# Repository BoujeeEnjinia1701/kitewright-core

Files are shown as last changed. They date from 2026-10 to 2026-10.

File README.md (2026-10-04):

# Kitewright Core

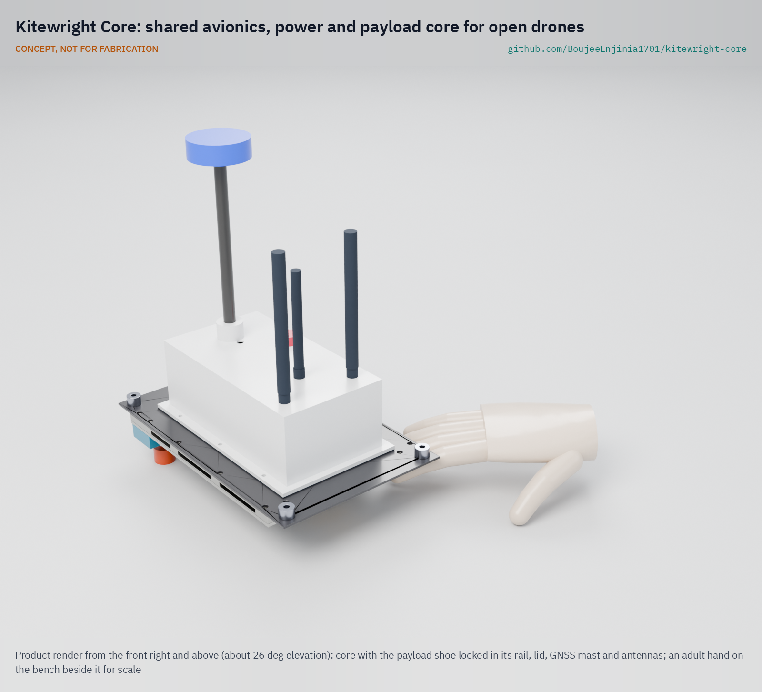
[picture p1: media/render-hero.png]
Kitewright Core: shared avionics, power and payload core, product render


     

**Area:** Aerial robotics · **TRL:** 3 of 9 (proof of concept on paper) · **Value-engineering target:** USD 5,000; estimated cost USD 3,946.80 · **Difficulty:** 4 of 5

The shared core of the Kitewright open drone family: open autopilot, ColdCell power bus and one standard payload mount.

## Concept rationale

Kitewright is an open civilian drone family built so that one set of avionics, one power bus and one payload mount serve every frame and every payload. Kitewright Core is that shared part: an autopilot running PX4 (ArduPilot as an alternative), a ColdCell power bus, radio links, a ground station setup and a single payload mount that carries both power and data. The Lift multirotor and the Range quadplane bolt onto it, and payloads such as AvalancheScout and LakeWatch plug into it. A fix or a tuning result found on one frame reaches all of them.

The core is tuned for the conditions that sparked the family: high, cold mountains such as Kashmir and the Himalaya, where Amish Chadha wants to fly. Our own first estimate is that at 5,000 m and -20 °C a multirotor hovers for only about 47% of its sea-level time (estimate, combining thinner air with cold battery capacity; to be checked on AltiRig). The core therefore treats cold power, altitude tuning and conservative failsafes as design inputs, not afterthoughts. The payload mount follows the open Pixhawk Payload Bus standard, DS-014, with a plain rail and locking pin, so third-party payloads can follow a published interface.

## Burning platform

Drones already save lives: DJI counted more than 1,000 people rescued with drone help worldwide by July 2023 ([DJI, 2023](https://www.dji.com/media-center/announcements/dji-records-more-than-1000-people-rescued-by-drones-globally)). In the high mountains they also carry loads: in April 2024 an unmodified DJI FlyCart 30 carried 15 kg between Everest Base Camp and Camp 1, at 5,300 to 6,000 m and -15 to 5 °C, in a 12 minute round trip that takes Sherpas 6 to 8 hours on foot through the icefall ([DJI, 2024](https://www.dji.com/media-center/announcements/dji-completes-world-first-drone-delivery-tests-on-mount-everest-en)). India has 189 high-risk glacial lakes above 4,500 m that field teams can reach only from June to September ([ThePrint, 2024](https://theprint.in/india/govt-approves-rs-150-crore-for-glacial-lake-outburst-flood-risk-mitigation-programme-for-4-states/2232525/)).

The platforms that can work there are closed and costly. A DJI Matrice 350 RTK costs USD 14,814 and uses its own payload and battery system ([Advexure](https://advexure.com/products/dji-matrice-350-rtk)); its self-heating TB65 batteries cost USD 899 each and are used in pairs ([DroneFly](https://www.dronefly.com/products/dji-tb65-intelligent-flight-battery-m350)). Air at 5,000 m in the standard atmosphere has a density of 0.736 kg/m3, 60% of sea level, and a temperature of -17.5 °C ([Engineering ToolBox](https://www.engineeringtoolbox.com/standard-atmosphere-d_604.html)). Open parts exist, such as PX4, licensed BSD 3-Clause ([PX4 on GitHub](https://github.com/PX4/PX4-Autopilot)), and the Pixhawk Payload Bus standard ([Dronecode, 2021](https://dronecode.org/announcing-the-pixhawk-payload-bus-open-standard/)), but no open core combines them into a documented, cold-rated base that a whole family of frames and payloads can share.

## Where it could be used

### By industry

| Industry | Use |
| --- | --- |
| Mountain and wilderness search and rescue | Search, thermal and transceiver payloads on a shared core that works at altitude |
| Disaster response and civil protection | Survey, line drop and supply delivery after floods and landslides |
| Glaciology, hydrology and climate research | Glacial lake and snowpack survey payloads (LakeWatch) on an open, inspectable platform |
| Mountain infrastructure (hydropower, roads, utilities) | Inspection and monitoring in high valleys |
| Universities and makerspaces | A documented reference core for teaching and payload development |

### By country or region

| Country or region | Why it matters there |
| --- | --- |
| India (Kashmir Himalaya) | A 2026 inventory found 155 glacial lakes, five with very high outburst susceptibility that threaten several thousand buildings, 15 major bridges and a hydropower project ([Journal of Glaciology, 2026](https://www.cambridge.org/core/journals/journal-of-glaciology/article/glacial-lake-outburst-flood-susceptibility-and-potential-downstream-implications-across-the-kas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)). |
| India (Himalayan states) | The national programme covers 189 high-risk lakes above 4,500 m, reachable on foot only from June to September ([ThePrint, 2024](https://theprint.in/india/govt-approves-rs-150-crore-for-glacial-lake-outburst-flood-risk-mitigation-programme-for-4-states/2232525/)); India's Drone Rules 2021 set the categories and Digital Sky process a civilian drone must follow ([PIB](https://static.pib.gov.in/writereaddata/specificdocs/documents/2022/jan/doc202212810701.pdf)). |
| Pakistan (Karakoram) | A small drone found Rick Allen alive on Broad Peak after 36 hours in 2018 ([Explorersweb, 2018](https://explorersweb.com/rick-allen-found-alive-on-broad-peak/)). |
| Nepal | Drone deliveries on Everest were tested at 5,300 to 6,000 m in 2024 and contracted by the government from May 2024 ([DJI, 2024](https://www.dji.com/media-center/announcements/dji-completes-world-first-drone-delivery-tests-on-mount-everest-en)). |
| United States | An average of 27 people a year have died in avalanches over the past decade ([CAIC](https://avalanche.state.co.us/accidents/statistics-and-reporting)); civilian drones there fly under FAA Part 107 ([FAA](https://www.faa.gov/uas/media/Part_107_Summary.pdf)). |

## What sparked the idea

In July 2018 the climber Rick Allen went missing high on Broad Peak in the Karakoram after a fall while descending. After 36 hours, Bartek Bargiel, who was filming a ski descent of K2, flew a small drone over the slope, spotted Allen alive at about 7,500 m and guided climbers to him ([Explorersweb, 2018](https://explorersweb.com/rick-allen-found-alive-on-broad-peak/)). The drone was a DJI Mavic Pro, flown far above its rated ceiling ([DroneDJ, 2018](https://dronedj.com/2018/07/16/mountaineer-rick-allen-was-feared-dead-on-broad-peak-but-a-dji-mavic-pro-drone-found-him-alive/)). Kitewright starts from that flight: an open family of drones, sharing one core, built for the mountains where it happened.

## Problem

Mountain and disaster teams who want drones for search, survey and delivery must buy closed platforms whose batteries, mounts and payloads work only with one maker. There is no open, documented core that a frame and its payloads can share, and that is set up for thin, cold air.

Full problem statement: [docs/01-problem.md](docs/01-problem.md)

## Concept

The shared core of Kitewright, an open drone family: an open autopilot on PX4, a ColdCell power bus, one standard payload mount carrying power and data (Pixhawk DS-014 with a plain rail and locking pin), radio and ground station, used by the Lift and Range frames and every payload.

Full design precis: [docs/02-concept.md](docs/02-concept.md) · Requirements: [docs/03-requirements.md](docs/03-requirements.md) · Calculations: [docs/04-calcs/01-sizing.md](docs/04-calcs/01-sizing.md) · Prototype build plan: [docs/05-build-plan.md](docs/05-build-plan.md) · Design decisions: [docs/06-design-decisions.md](docs/06-design-decisions.md) · General arrangement: [cad/drawings/KWC-DWG-001.pdf](cad/drawings/KWC-DWG-001.pdf)

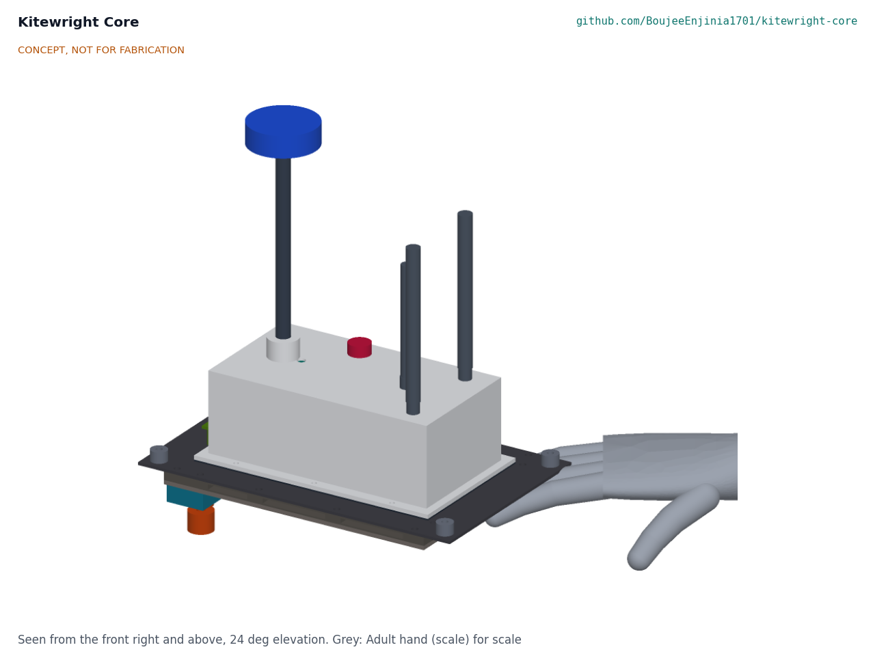
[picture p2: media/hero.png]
Concept, seen from the front right and above, with an adult hand for scale


At TRL 3 the core meets all eleven requirements on paper: the rail and two locking pins carry a 5 kg payload with factors of 8 or more, a gloved payload swap takes about 52 s, 100 W reaches the payload, and the avionics stay within their ratings from -20 to +45 °C. With a carbon fibre plate, lightened rails and the power leads moved into each frame's harness (Amish's decision of 2026-10-03), the core is estimated at 0.99 kg against R9's 1.0 kg. R8 is restated so that a core moving between Lift and Range has its frame's power harness resoldered at the bench (Amish's decision of 2026-10-04), and the frames now carry the core to one shared mounting envelope. The hover-time model gives 47 % of sea-level hover time at 5,000 m and -20 °C with cold packs and 70 % with ColdCell packs (estimates).

## Key components

- Flight controller (Pixhawk standard)
- GNSS receiver and compass
- ColdCell power bus and power distribution board
- Payload mount (plain rail, locking pin, DS-014 connector)
- Telemetry radio and control link
- Ground station kit
- Optional companion computer
- Cold-rated harness and avionics enclosure
- Altitude parameter sets

## Building the prototype

The prototype is one core: a 2 mm carbon fibre plate carrying the avionics under a printed lid, with a plain rail, two front stops and two spring locking pins underneath, and one payload shoe. Nine parts are made, the carbon plate by a cutting service and the others with a saw, drill, small mill, tap and 3D printer; everything else is bought, and each frame brings its own power leads. The [prototype build plan](docs/05-build-plan.md) gives a making sketch for every made part, close-ups of every joint, eleven assembly steps with pictures, first checks and safety stops. It is a plan, not yet built.

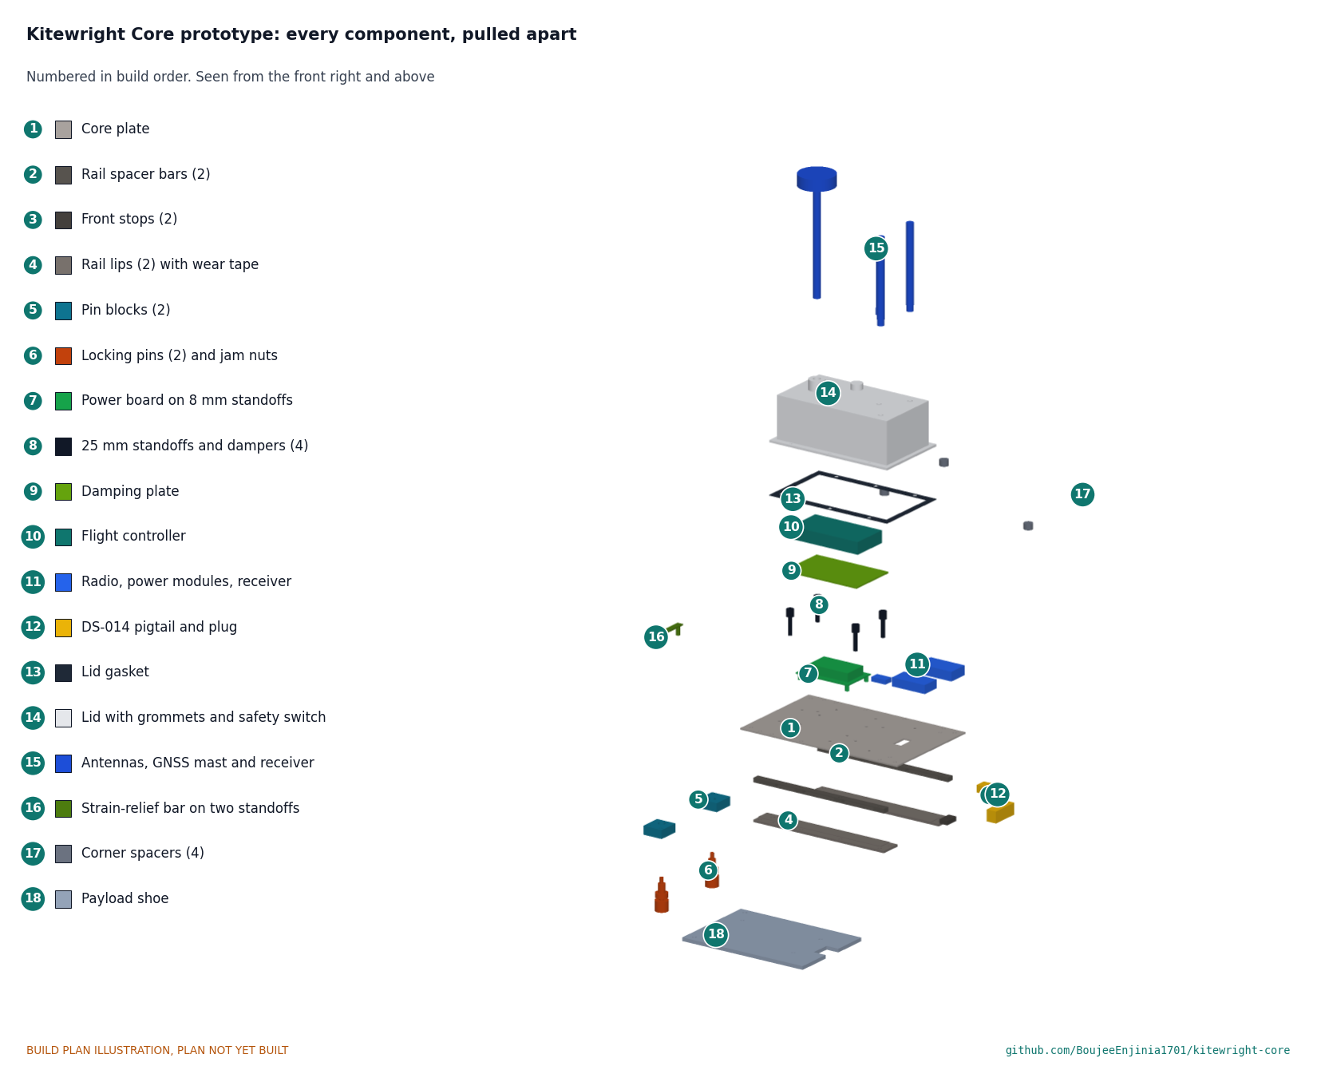
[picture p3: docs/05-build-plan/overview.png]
Every component, pulled apart and numbered in build order


## Safety

> Published as an open engineering reference, not certified aviation equipment.
>
> Civilian use only. No weapons, targeting or military payloads, and none will be accepted into the family.
>
> Certification and operating approvals (FAA Part 107 in the United States, EASA rules in Europe, India's DGCA Drone Rules 2021) are out of scope at this TRL and will be addressed if prototypes progress. Builders must fly only where local rules allow.
>
> Propellers can cause serious injury: arm only in a clear area, and write pre-flight, arming and keep-out procedures before any powered test.
>
> Lithium battery packs can catch fire after a crash, over-charge or cold charging; follow ColdCell safety rules. The core carries up to 60 V and 200 A peak: power it first from a current-limited bench supply, and connect packs only through the keyed anti-spark connectors.
>
> Loss of link or power in thin air can mean a crash in remote terrain: return-to-launch, low-battery and geofence failsafes must be set and tested at each altitude band.
>
> Payloads must be locked and pin-checked before flight; a released payload is a falling object. Two independent locking pins are fitted; neither may show its red band, and the payload is tugged, before every flight.
>
> This design is published as an open engineering reference. It is a TRL 3 concept, not for fabrication, and not certified equipment.

## Repository layout

| Folder | Contents |
| --- | --- |
| `docs/` | Problem, concept, requirements, calculations and design decisions |
| `cad/src/` | build123d Python source, the source of truth for all geometry |
| `cad/step/`, `cad/stl/` | Exported models for FreeCAD, other CAD tools and printing |
| `cad/drawings/` | 2D sketches and dimensioned drawings |
| `bom/` | Bill of materials |
| `electronics/` | KiCad schematics and PCB layouts |
| `firmware/` | Microcontroller code |
| `media/` | Renders, perspectives and photos |
| `build-log/` | Dated prototyping notes |

## Documentation

Controlled documents follow the portfolio [documentation standard](.kit/STANDARDS.md). Each carries a document ID (KWC-PRC-001 for the precis), a version and a revision history. Branded PDFs are built with `python .kit/render.py` and attached to GitHub Releases when a document is tagged, for example `KWC-PRC-001/v1.0`.

## Credits

Designed by Amish Chadha at Design Molecule Labs. See [CONTRIBUTORS.md](CONTRIBUTORS.md) for roles. To cite this design, use [CITATION.cff](CITATION.cff) (GitHub shows it as "Cite this repository").

AI assistance (Claude) was used to accelerate prototype documentation and first-pass research. Design direction and all decisions are Amish Chadha's, recorded in this repository's decision records (`docs/decisions/`).

## Licenses

- **Hardware** (CAD, drawings, BOM, electronics): [CERN-OHL-S v2](LICENSE)
- **Software** (firmware, scripts, notebooks): [MIT](LICENSE-SOFTWARE)

A project of the [Design Molecule](https://designmolecule.com) lab.

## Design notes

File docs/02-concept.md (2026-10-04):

---
doc_id: KWC-PRC-001
title: Kitewright Core design precis
project: Kitewright Core
doc_type: Precis
version: "0.3"
status: Draft
date: '2026-10-03'
author: Amish Chadha
license: CERN-OHL-S-2.0
revisions:
- version: "0.1"
  date: '2026-09-30'
  author: Amish Chadha
  change: Initial scaffold
- version: "0.2"
  date: '2026-10-03'
  author: Amish Chadha
  change: TRL 2 and TRL 3 precis on the constructable design; decisions of KWC-DDR-001 and KWC-DDR-002 under Amish's 2026-10-03 pre-approval; numbers from KWC-CAL-001
- version: "0.3"
  date: '2026-10-03'
  author: Amish Chadha
  change: Amish's decision 33B (KWC-DDR-003); carbon plate, power leads in the frames' harness; mass and cost from KWC-CAL-001 v0.2
---

# Kitewright Core design precis

The shared core of the Kitewright open drone family: open autopilot, ColdCell power bus and one standard payload mount.

## Summary

Kitewright Core is a 240 x 150 mm carbon fibre plate that hangs under a frame's deck on four M4 bolts. On top, under a printed lid that rises through an opening in the deck, sit a Pixhawk-standard flight controller on vibration dampers, a power distribution board for two ColdCell packs, two independent 5.3 V supplies, a payload power switch, a telemetry radio and a control link receiver. A GNSS receiver stands on a removable mast above the lid. Under the plate is the payload mount: a plain rail of aluminium bars in which a 5 mm payload shoe slides from the rear to two front stops and is held by two spring locking pins, with the DS-014 power and data plug on a short pigtail. The same core, unchanged, flies Kitewright Lift and Kitewright Range with published parameter sets for three altitude bands. On paper it meets all eleven requirements; its estimated mass is 0.99 kg against R9's 1.0 kg after Amish's decision 33B on 2026-10-03 (Figure 1, KWC-CAL-001).

Figure 1. Kitewright Core concept, seen from the front right and above, with an adult hand for scale

*Figure 1. Kitewright Core, generated from the parametric model. CONCEPT, NOT FOR FABRICATION.*

## How it works

ColdCell packs plug into the two AS150 inputs of the frame's power harness, which Kitewright Lift or Range supplies and which enters the lid at the back (decision 33B). The power distribution board joins them, measures total current with a Hall sensor and feeds the frame's speed controllers through two AS150 outputs. Two independent supplies, a digital power monitor and a backup supply, each turn the 18 to 60 V bus into 5.3 V for the flight controller, so one failure does not drop the avionics. A payload switch, enabled by the flight controller, feeds the bus to the payload's battery pins through the DS-014 pigtail with an 8 A limit.

The flight controller runs released PX4 with Kitewright parameter sets. It reads the packs' temperature and charge over DroneCAN from ColdCell's battery management system, the GNSS and compass on the mast, and the barometer on its own board, and it talks to the ground station over a 900 MHz class telemetry radio and to the pilot's handset over a long-range control link.

A payload carries a 184 x 128 x 5 mm aluminium shoe on its top. The operator pulls and twists both locking pins to their rest, slides the shoe into the rail from the rear until it stops against the front stops, and twists the pins back: they snap up into the shoe's two holes. The DS-014 plug is then pushed into the payload's socket, and the flight controller recognises the payload over MAVLink. The shoe's edges run between the plate and the taped lips with a 0.3 mm gap, so the lips carry its weight; the pins and front stops hold it fore and aft.

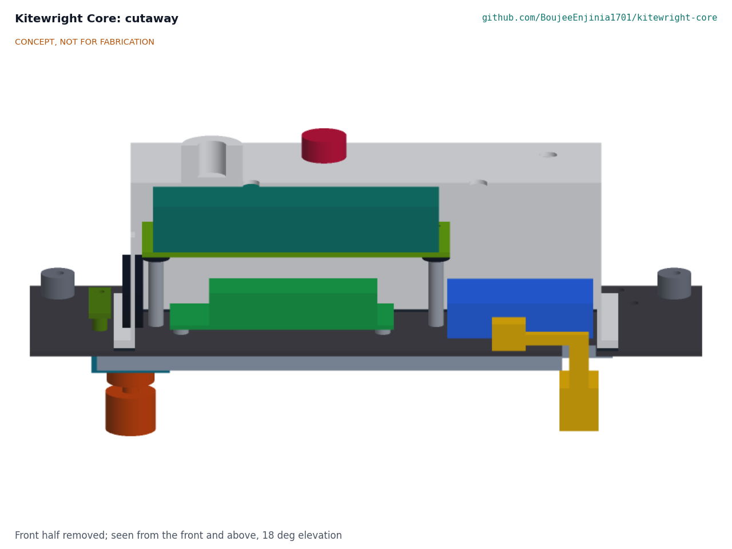
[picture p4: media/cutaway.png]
Figure 2. Cutaway on the centre line


*Figure 2. Cutaway, front half removed: the damped flight controller above the power board, and the rail and shoe below the plate.*

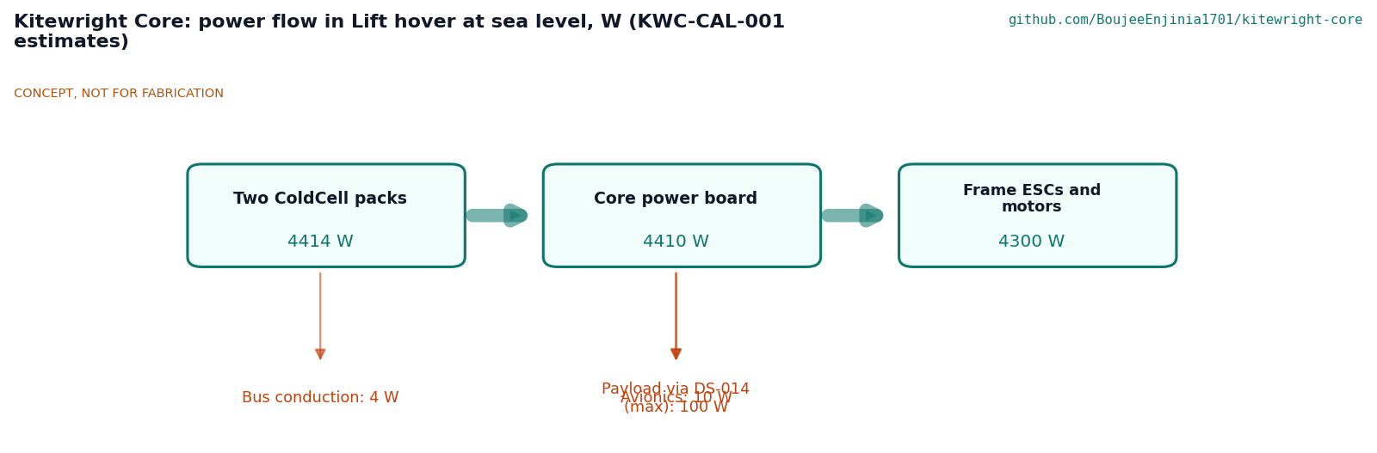
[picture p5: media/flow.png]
Figure 3. Power flow


*Figure 3. Power flow in Kitewright Lift's hover at sea level (KWC-CAL-001 estimates).*

## Main components

*Table 1. Components, numbered as in `bom/bom.csv` and Figure 4.*

| # | Component | Role |
| --- | --- | --- |
| 1 | Core plate, 240 x 150 x 2 mm carbon fibre | Carries everything; bolts to the frame on a 220 x 130 mm pattern |
| 2 | Corner spacers (4), 16 x 8 mm | Hold the plate 8 mm under the frame deck |
| 3, 4, 5 | Rail spacer bars, lips and wear tape | The plain rail: 200 mm long, 19 mm lip overlap, 0.3 mm running gap |
| 6 | Front stops (2) | End of travel, where both pins line up with their holes |
| 7, 8 | Pin blocks and locking pins (2) | Two independent spring plungers; a red band shows a withdrawn pin |
| 9 | Payload shoe | Fitted to every payload; the core kit carries one |
| 10, 11 | Lid and gasket | Printed ASA cover with mast boss, antenna, switch and grommet holes |
| 12, 13, 14 | Damping plate, dampers, standoffs | Isolate the flight controller from vibration |
| 15 | Flight controller, FMUv6X class | Runs PX4; triple IMU with heater; 16 outputs; Ethernet and CAN |
| 16, 17 | GNSS receiver and compass, mast | Position and heading, 231 mm above the plate, clear of power wiring |
| 18, 19 | Power distribution board, power modules | Pack inputs, frame outputs, current sensing, two 5.3 V supplies, payload switch |
| 20 | Clinch nuts (14) | Flush threads under the plate where the shoe slides |
| 21 | Strain-relief bar | Holds the frame's four 8 AWG power leads behind the lid; the leads and AS150 plugs belong to each frame (decision 33B) |
| 22, 23, 24 | Telemetry radio, control link receiver, antennas | Command, telemetry and control path |
| 25 | DS-014 connector pair and pigtail | Power and data to the payload |
| 26 to 29 | Safety switch, grommets, harness, fasteners | Arming safety, cable entries, cold-rated wiring |
| 30 | Companion computer (optional) | Payload processing in its own box on the frame, over Ethernet |
| 31 to 34 | Handset, ground station tablet, ground antenna, field charger | Ground station kit |
| 35 | Spares kit | Field spares |

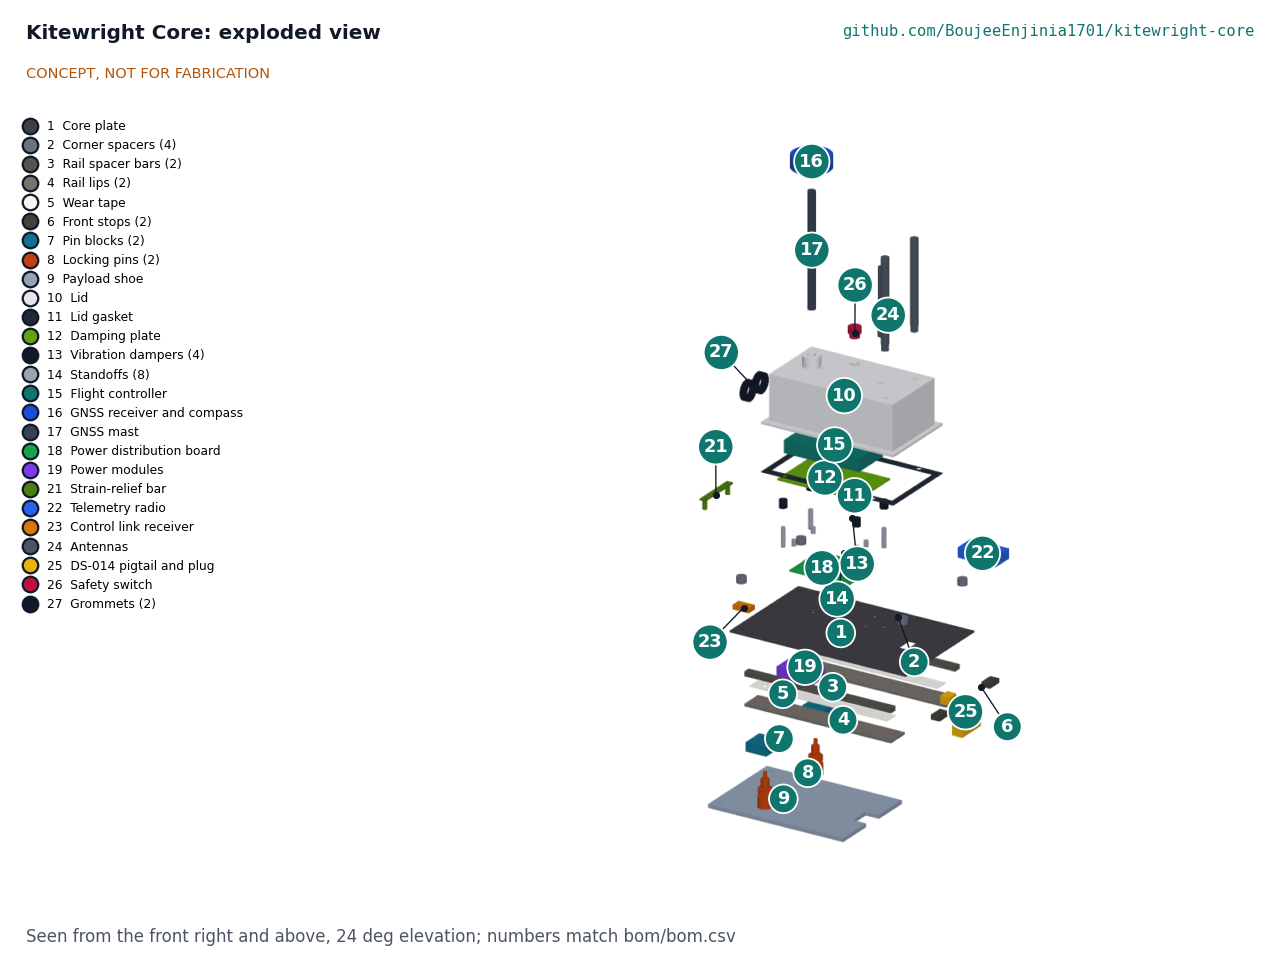
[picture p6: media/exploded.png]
Figure 4. Exploded view


*Figure 4. Exploded view; numbers match `bom/bom.csv`.*

## Numbers from the TRL 3 calculations

*Table 2. Key figures (KWC-CAL-001).*

| Quantity | Value | Basis |
| --- | --- | --- |
| Rated payload | 5 kg; vertical design load 147 N | R3 |
| Lowest strength factor | 10.8 (plate edge as a beam between frame bolts) | CAL section A |
| Fore-aft load on one pin alone | 221 N; 11.2 MPa shear in a 5 mm pin | CAL section A |
| Payload swap with gloves | About 52 s, no tools | CAL section B |
| Payload current for 100 W | 5.6 A at 18 V (6S), 2.2 A at 44.8 V | CAL section C |
| Hottest part at 45 °C ambient | About 75 °C (parts rated 85 °C) | CAL section D |
| Air density at 5,000 m | 0.736 kg/m³, 60 % of sea level | CAL section E |
| Hover time at 5,000 m and -20 °C | 47 % of sea level with cold packs; 70 % with ColdCell | CAL section F |
| Flight controller outputs used | Lift 11, Range 10, of 16 | CAL section G |
| Core mass | About 0.99 kg (R9 met on paper, 10 g margin) | CAL section H |
| Cost | USD 3,946.80 with ground station and spares | CAL section I |

Value-engineering target: USD 5,000. Estimated cost of the constructable design: USD 3,946.80 (USD 1,053.20 under the target).

## Key design choices

All decided under Amish's 2026-10-03 pre-approval; each is argued in KWC-DDR-001 or KWC-DDR-002 and indexed in the design decisions register, KWC-DEC-001.

- **PX4 first, ArduPilot as the documented alternative** (D1), on a Pixhawk FMUv6X class controller (D2).
- **One bus, 18 to 60 V** (D3), so a 6S Range and a 12S or 16S Lift use the same board, supplies and switch.
- **One payload class for version 1: 5 kg and 100 W** (D4).
- **Plain rail, rear entry, front stops, pigtail plug** (D5); no bayonet and no blind-mating connector.
- **Two independent locking pins** (D6), the conservative safety choice; either holds the payload alone.
- **Core hangs under the frame deck** (D7) on a 220 x 130 mm M4 pattern; the lid rises through a 200 x 112 mm opening.
- **Companion computer outside the core** (D8), so its heat and mass stay with the frames that need it.
- **ColdCell reports over DroneCAN** (D9), which released PX4 reads without changes.

## Patent design-arounds

From the preliminary patent, trademark and prior-art screen (not legal advice), all kept in the constructable design:

- Payload mount uses the Pixhawk DS-014 connector with a plain rail and locking pins, no bayonet, to stay clear of DJI US 2021/0316882 (payload mounting platform, claims unread). DJI US9890900B2 (quick gimbal connector) is expired.
- ColdCell packs use an external film heater on standard cells with a BMS thermostat, not in-cell resistor sheets (EC Power US9882197B2, to 2036). The core only reads the packs.
- Any tether input to the power bus is a fixed-voltage supply with onboard DC-DC conversion, not adaptive tether voltage (Elistair US11059580B2, to 2037). The core's 18 to 60 V inputs take a fixed-voltage tether converter like a pack.
- Attorney claim reads before any sale: DJI 2021/0316882, US9882197, US11059580.

## Relationship to other lab projects

- ColdCell (heated battery packs; reports over DroneCAN on the core's bus)
- AltiRig (thin-air propeller and motor test chamber; supplies the hover-thrust data for Table 6 of KWC-CAL-001)
- Kitewright Lift and Kitewright Range (host frames; provide the deck pattern and opening of D7)
- AvalancheScout and LakeWatch (payloads; each carries a shoe of KWC-DWG-106 and a DS-014 socket)

## Safety

> **Safety:** Published as an open engineering reference, not certified aviation equipment. Civilian use only. No weapons, targeting or military payloads, and none will be accepted into the family.
>
> **Safety:** Certification and operating approvals (FAA Part 107 in the United States, EASA rules in Europe, India's DGCA Drone Rules 2021) are out of scope at this TRL and will be addressed if prototypes progress. Builders must fly only where local rules allow.
>
> **Safety:** Lithium packs: the core carries up to 60 V and 200 A peak from two packs. Connect packs only through the anti-spark AS150 connectors, check polarity on a current-limited bench supply first, never charge a pack below its charge temperature (ColdCell blocks this), and keep a lithium fire plan at hand. A crashed pack can catch fire hours later.
>
> **Safety:** Moving machinery: propellers on the frames can cause serious injury. The core's safety switch must be pressed before arming; arm only in a clear area, and write pre-flight, arming and keep-out procedures before any powered test.
>
> **Safety:** Falling payload: a released payload is a falling object. Two independent locking pins are fitted; both must show no red band, and the payload is tugged, before every flight. Nobody stands under a payload being lifted.
>
> **Safety:** Loss of link or power in thin air can mean a crash in remote terrain: return-to-launch, low-battery and geofence failsafes must be set and tested at each altitude band (KWC-CAL-001, Table 6).

This design is published as an open engineering reference. It is not certified equipment.

## Open questions

None for design. Facts that can only be settled with parts in hand (the DS-014 licence, pinout and pin rating, the controller's mounting pattern, plunger stroke) are listed under "To confirm when parts are bought" in KWC-DEC-001. R9 core mass awaits Amish's decision (`docs/REVIEW.md`).

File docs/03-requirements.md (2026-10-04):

---
doc_id: KWC-REQ-001
title: Kitewright Core requirements
project: Kitewright Core
doc_type: Requirements
version: "0.4"
status: Draft
date: '2026-10-04'
author: Amish Chadha
license: CERN-OHL-S-2.0
revisions:
- version: "0.1"
  date: '2026-09-30'
  author: Amish Chadha
  change: Initial scaffold
- version: "0.2"
  date: '2026-10-03'
  author: Amish Chadha
  change: TRL 3 status of every requirement from KWC-CAL-001; rated payload class and bus voltage window stated (KWC-DDR-001); targets unchanged
- version: "0.3"
  date: '2026-10-03'
  author: Amish Chadha
  change: Amish's decision 33B carried out (KWC-DDR-003); status of R3, R8, R9 and R11 updated from KWC-CAL-001 v0.2; R9 now met on paper; targets unchanged; R8 harness point open (O2)
- version: "0.4"
  date: '2026-10-04'
  author: Amish Chadha
  change: R8 restated under Amish's round-3 decision 7A (KWC-DDR-004); register item O2 closed; all eleven requirements met on paper or by design
---

# Kitewright Core requirements

The requirements below are unchanged in their targets from version 0.1. Each carries its TRL 3 status from the sizing calculations, KWC-CAL-001 v0.2, on the constructable design of KWC-DDR-002 as lightened under decision 33B (KWC-DDR-003). On 2026-10-03 Amish decided R9 core mass as recommended ("i agree with all the 46 recommendations you provided. please proceed."): a lighter structure, with the power leads moved out of the core into the frames. All eleven requirements are met on paper or by design. On 2026-10-04 Amish decided R8 as recommended (round 3, item 7A): Amish Chadha (owner) on 2026-10-04: "For round 3, I agree with all your proposed recommendations". A core moved between Lift and Range now has its frame's power harness changed at the bench, and R8 is restated to say so (KWC-DDR-004).

> **Safety:** The core carries lithium pack power of up to 60 V and 200 A, and holds payloads that would fall if released in flight. Requirements R3 and R5 and the build plan's safety stops cover these; none of the figures here is a safety approval.

Table 1. Requirements

| ID | Requirement | Target | Verification (TRL 3 or later) | TRL 3 status (KWC-CAL-001) |
| --- | --- | --- | --- | --- |
| R1 | Payload electrical interface | DS-014 40-pin connector with all required signals and battery power present and documented | Continuity and protocol test with a reference payload on the bench | Met on paper; licence and pinout to confirm from the standard |
| R2 | Payload swap | Swap in 60 s or less without tools, with locking pin engaged and visible (target) | Timed field trials with gloved users | Met on paper: about 52 s with gloves (estimate) |
| R3 | Mount strength | Holds 3 times the rated payload mass statically and 1.5 times under a 2 g drop (target) | CalRig proof-load and drop test | Met on paper: factor 8 or more on every part at 147 N, carbon plate included |
| R4 | Payload power | At least 100 W continuous to the payload at bus voltage (target) | Load bank test at -20 and +45 °C | Met on paper: at most 5.6 A; DS-014 pin rating to confirm |
| R5 | Operating temperature | Avionics boot and fly from -20 to +45 °C (target) | Climatic chamber soak and bench run | Met on paper: hottest part about 75 °C, cold boot within rating |
| R6 | Altitude envelope | Stable control and failsafes at air density equivalent to 5,000 m (target) | AltiRig tests, then field flights at a high site | Met on paper for the core; flight check needs a frame |
| R7 | Performance model | Published hover time model predicts measured hover time within 15% at each altitude band (target) | Compare model to AltiRig and flight logs | Model published; accuracy shown only at TRL 4 |
| R8 | Common core | Same core flies Lift and Range with parameter changes and a change of the frame's power harness at the board (a bench change, lid off, about 30 min); restated 2026-10-04, decision 7A | Build both frames and fly from one core set; time the bench harness change | Met by design as restated: same firmware, same 220 x 130 mm fixing (Kitewright interface table), four 8 AWG leads resoldered at the board |
| R9 | Core mass | Avionics, radios and mount 1.0 kg or less, excluding batteries (target) | Weigh the assembled core | Met on paper: 0.99 kg estimated, 10 g margin (decision 33B); bought-part masses to confirm |
| R10 | Upstream firmware | Runs a released PX4 version with no source changes, parameters and modules only | Build check against the PX4 release tag | Met by design |
| R11 | Prototype cost | USD 5,000 or less including ground station and spares | Bill of materials and receipts | USD 3,946.80, under the value-engineering target by USD 1,053.20 |

## Definitions fixed at TRL 3

- **Rated payload:** 5 kg on the mount, one payload class for version 1, so R3's load cases are 147 N vertical (KWC-DDR-001, D4).
- **Bus voltage:** 18 to 60 V at the core's pack inputs, from 6S Li-ion to 16S LiFePO4 (KWC-DDR-001, D3).
- **Core mass (R9):** the airborne core as built, excluding batteries, the payload shoe (each payload carries its own), the optional companion computer (carried outside the core, KWC-DDR-001, D8) and, since decision 33B, the frame's power leads and AS150 plugs, which belong to each frame's harness (KWC-DDR-003).
- **Prototype cost (R11):** treated as a value-engineering target, not a limit (STANDARDS section 18).

## Requirements at risk

- R9 is met on paper with a 10 g margin after decision 33B; bought-part masses are catalogue-class values, so weighing them when bought (register, T9) decides it.
- R2 has a small margin (about 52 s); a gloved timed trial at TRL 4 decides it.
- R1 and R4 depend on the DS-014 licence, pinout and pin rating, to be confirmed from the published standard (register, To confirm).

## Assumptions

- The 47% hover time at 5,000 m and -20 °C is a first estimate, not a measurement; KWC-CAL-001 traces it to unheated packs and gives 70 % with ColdCell packs.
- Pixhawk-standard flight controllers and DS-014 connectors can be bought in small quantities.
- PX4 supports the needed multirotor and quadplane modes without source changes.
- ColdCell can keep packs above their minimum discharge temperature for a full flight.

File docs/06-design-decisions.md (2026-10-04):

---
doc_id: KWC-DEC-001
title: Kitewright Core design decisions register
project: Kitewright Core
doc_type: Design decisions register
version: "0.3"
status: Draft
date: '2026-10-04'
author: Amish Chadha
license: CERN-OHL-S-2.0
revisions:
  - version: "0.1"
    date: '2026-10-03'
    author: Amish Chadha
    change: Register opened at TRL 3; decisions D1 to D15 and C1 to C10 made under Amish's 2026-10-03 pre-approval; R9 core mass open for Amish
  - version: "0.2"
    date: '2026-10-03'
    author: Amish Chadha
    change: O1 decided by Amish as option B (round 2 item 33B, KWC-DDR-003) and moved to Decisions made; new item O2 (R8 harness change) proposed; T7 reworded for the carbon plate; cost updated
  - version: "0.3"
    date: '2026-10-04'
    author: Amish Chadha
    change: O2 decided by Amish as option A (round 3 item 7A, KWC-DDR-004) and moved to Decisions made; R8 restated
---

# Kitewright Core design decisions register

Every design decision still to be made, and every decision made, in one place. Each decision is argued in full in its decision record under `docs/decisions/`; this register is the index Amish works from. The build plan (`docs/05-build-plan.md`) describes the design as it stands and does not list open decisions.

> **Safety:** Decisions D3, D6 and D7 set the lithium power path, the payload retention and the load path into the frame. Any change to them reopens the build plan's safety stops.

## Open decisions

None. Amish decided O2 (R8, the frame harness change) on 2026-10-04 as option A; see Decisions made and KWC-DDR-004. Nothing in carrying it out needs Amish.

## To confirm when parts are bought

| # | What to confirm | Why it matters | Source |
| --- | --- | --- | --- |
| T1 | DS-014 licence terms | Whether the connector and pinout may be reused in an open design (D12) | KWC-PRB-001 |
| T2 | DS-014 connector part numbers, pinout and current per battery pin | R1 and R4: 100 W at 6S needs 5.6 A across the battery pins | KWC-CAL-001 section C |
| T3 | Flight controller size and mounting pattern | Damping plate holes and lid headroom (5 mm or more) | KWC-DWG-108 |
| T4 | Indexing plunger stroke (at least 9 mm) and pin length | The pin must clear the shoe when withdrawn and enter it 4.5 mm when released | KWC-DWG-105 |
| T5 | Damper hardness for the controller's mass | Vibration isolation | Build plan 3.9 |
| T6 | Power board, power module and radio footprints | Layout inside the lid; clearances checked in the model | `cad/src/model.py` |
| T7 | M3 countersunk heads in the 2 mm carbon plate: flush seating and no pull-through (0.4 mm land under each head); bonded flush inserts as the fallback | Flush underside where the shoe slides 0.3 mm below (KWC-DDR-003) | KWC-DWG-101 |
| T8 | Telemetry band and power allowed at the first site (India: 865 to 867 MHz candidate) | Radio choice (D10) | KWC-DDR-001 |
| T9 | Bought-part masses | R9 is met by only 10 g on catalogue class values | KWC-CAL-001 section H |
| T10 | Carbon plate laminate and price from the cutting service (3K twill, quasi-isotropic, 2 mm) | 250 MPa bending and 200 MPa bearing allowables; USD 58 estimate | KWC-CAL-001 section A; `bom/bom.csv` line 1 |

## Value engineering

Value-engineering target: USD 5,000 (a hypothetical control target, not a limit). Estimated cost of the constructable design: USD 3,946.80 (USD 1,053.20 under the target). Main cost drivers: the rugged ground station tablet (USD 900), the spares kit (USD 560), the telemetry radio pair (USD 400), the flight controller (USD 390), the field charger (USD 350) and the control handset (USD 250); the made parts cost about USD 150 in all, the carbon plate (USD 58) the largest of them. Savings worth trying: a tablet the team already owns if it is rated to -20 °C, a control link with built-in MAVLink telemetry in place of the separate radio pair (about USD 400), and a smaller spares kit once the first core has flown.

## Decisions made

D1 to D15 and C1 to C10 were decided by Amish under his pre-approval of 2026-10-03: "start with the first 14 repos from the list of 29 projects. I pre-approve the batch runs along with any recommendations you come up with. I also accept any cost overruns or variations from the assumed scope cost." and "Proceed with the remaining 15 scaffolds".

| Date | Decision | Decided by | Record |
| --- | --- | --- | --- |
| 2026-10-03 | D1: PX4 for the whole family; ArduPilot documented as the alternative | Amish (pre-approval) | KWC-DDR-001 |
| 2026-10-03 | D2: Pixhawk FMUv6X class flight controller | Amish (pre-approval) | KWC-DDR-001 |
| 2026-10-03 | D3: 18 to 60 V bus, two pack inputs, two frame outputs, AS150 connectors | Amish (pre-approval) | KWC-DDR-001 |
| 2026-10-03 | D4: one payload class for version 1, 5 kg and 100 W | Amish (pre-approval) | KWC-DDR-001 |
| 2026-10-03 | D5: plain rail, rear entry, front stops, hand-plugged DS-014 pigtail | Amish (pre-approval) | KWC-DDR-001 |
| 2026-10-03 | D6: two independent locking pins with red bands (conservative; a vibration and pull test on the built mount could relax it to one) | Amish (pre-approval) | KWC-DDR-001 |
| 2026-10-03 | D7: core hangs under the frame deck, 220 x 130 mm M4 pattern, 200 x 112 mm deck opening | Amish (pre-approval) | KWC-DDR-001 |
| 2026-10-03 | D8: optional companion computer in its own box on the frame | Amish (pre-approval) | KWC-DDR-001 |
| 2026-10-03 | D9: ColdCell reports over DroneCAN | Amish (pre-approval) | KWC-DDR-001 |
| 2026-10-03 | D10: 900 MHz class radios set per country; India 865 to 867 MHz as first candidate | Amish (pre-approval) | KWC-DDR-001 |
| 2026-10-03 | D11: three altitude parameter bands | Amish (pre-approval) | KWC-DDR-001 |
| 2026-10-03 | D12: proceed with DS-014 and confirm its licence; own open pinout as fallback | Amish (pre-approval) | KWC-DDR-001 |
| 2026-10-03 | D13: first co-design candidate to approach, a university glaciology group in Jammu and Kashmir (not agreed) | Amish (pre-approval) | KWC-DDR-001 |
| 2026-10-03 | D14: log every flight; remote ID module on CAN when required | Amish (pre-approval) | KWC-DDR-001 |
| 2026-10-03 | D15: publish the hover-time model | Amish (pre-approval) | KWC-DDR-001 |
| 2026-10-03 | C1 to C10: design for construction (rail, pins, stops, pigtail, clinch nuts, frame fixing, damping, lid, leads, mast) | Amish (pre-approval) | KWC-DDR-002 |
| 2026-10-03 | O1 (round 2 item 33B): R9 core mass, option B. Lighter structure (carbon plate with countersunk M3 fixings in place of clinch nuts, pocketed rail bars, 12 mm pin blocks, 12 mm corner spacers, 1.5 mm lid walls) and the power leads and AS150 plugs moved to each frame's harness, with a strain-relief bar on the core: 0.99 kg (R9 met on paper), USD 6.20 more in all. Amish: "i agree with all the 46 recommendations you provided. please proceed." | Amish | KWC-DDR-003 |
| 2026-10-04 | O2 (round 3 item 7A): R8 common core, option A. Accept a bench change of the frame's power harness when a core moves between Lift and Range (lid off, four 8 AWG leads desoldered and the other frame's soldered on, about 30 min); R8 restated as "same core flies Lift and Range with parameter changes and a change of the frame's power harness at the board". No hardware change; R9 stays met. Amish: "For round 3, I agree with all your proposed recommendations" | Amish | KWC-DDR-004 |

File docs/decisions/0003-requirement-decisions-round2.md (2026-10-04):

---
doc_id: KWC-DDR-003
title: Kitewright Core requirement decisions, round 2
project: Kitewright Core
doc_type: Design decision record
version: "0.1"
status: Draft
date: '2026-10-03'
author: Amish Chadha
license: CERN-OHL-S-2.0
revisions:
- version: "0.1"
  date: '2026-10-03'
  author: Amish Chadha
  change: Decision O1 (R9 core mass) decided by Amish as recommended, option B, and carried into the model, calculations, BOM, drawings and build plan
---

# 0003: Requirement decisions, round 2

- **Date:** 2026-10-03
- **Status:** Decided. Decided by Amish Chadha on 2026-10-03: "i approve all of the 47 recommendations provided by you. Execute them." Each decision below is the recommended option, exactly as worded, including its conditions.

## Context

The TRL 3 calculations (KWC-CAL-001 v0.1) left one requirement not met on paper: R9, core mass. It was posed to Amish in `docs/REVIEW.md` and in the design decisions register (KWC-DEC-001) as open decision O1, with options and a recommendation. Amish approved every recommendation on 2026-10-03. This record states what was chosen, what it changed and the condition it carries. The decision also changes Kitewright Lift and Kitewright Range, which now own the power leads; the matching record in Kitewright Lift is KWL-DDR-003.

## Options considered

*Table 1. Decision O1 (global decision 17), as posed.*

| Option | What changes | Effect on R9 | Cost | Mass |
| --- | --- | --- | --- | --- |
| A | Lighter structure: 2 mm carbon fibre plate, 1.5 mm lid walls, pocketed rail bars | About 1.12 kg, still not met | About USD 60 more | 157 g less |
| B | A, plus the pack and frame leads and AS150 plugs moved to each frame's harness | About 0.99 kg, met | About USD 60 more on the core; USD 60 of leads move to the frames | 281 g less |
| C | Keep the design as drawn | 1.27 kg, not met | None | None |

## Decision

*Table 2. Decision, effect and condition.*

| # | Requirement | Option chosen | Effect | Condition |
| --- | --- | --- | --- | --- |
| O1 (17) | R9, core mass | **B**: lighter structure (2 mm carbon fibre plate, 1.5 mm lid walls, pocketed rail bars) and the pack and frame leads with their AS150 plugs moved to each frame's harness; the core keeps the power board's solder pads and a strain-relief bar | Core 0.996 kg against the 1.0 kg of R9: met on paper with a 4 g margin (was 1.27 kg). 278 g less: plate 81 g, lid 24 g, rail bars 52 g, leads 121 g net of the 3 g bar, inserts 1 g. Every strength factor stays above 5 (lowest 6.8, the side beam at a pocket). Core cost USD 59.80 more; USD 56 of leads and plugs leave the core; total USD 3,944.40 (was USD 3,940.60) | The decision's own conditions: R9 met with a small margin, every strength factor above 5, and Kitewright Lift and Kitewright Range own their power leads. Both hold on paper. The 4 g margin is inside the accuracy of the catalogue masses, so the built core is weighed at TRL 4 |

## Consequences

- `cad/src/model.py`: the plate is carbon fibre (same 240 x 150 x 2 mm); the spacer bars have three windows each with 1.5 mm walls and the lips three 2 mm pockets underneath, all with at least 4.25 mm of solid bar round every hole; the lid walls and top are 1.5 mm; the leads and AS150 plugs are no longer core parts; a G10 strain-relief bar on two 11 mm posts sits behind the lid; the frame's leads are drawn as context to check that they reach the pads, the grommets and the bar. 646 constructability checks pass.
- Clinch nuts cannot be pressed into carbon plate, so the 14 clinch nuts become 16 bonded flush inserts (two more for the bar posts). They sit flush underneath, where the shoe runs 0.3 mm below the plate. This is a direct consequence of the carbon plate; it is listed as a new item to confirm (KWC-DEC-001, To confirm, T10).
- `docs/04-calcs/sizing.py` and KWC-CAL-001 v0.2: sections A and H recalculated; R9 now met on paper; the lowest strength factor is 6.8.
- `bom/bom.csv`: line 1 carbon plate (USD 62), lines 3 and 4 pocketed (USD 7 and USD 8 each), line 10 lid (USD 5), line 20 bonded inserts (16 at USD 0.65, estimate), line 21 strain-relief bar (USD 4) in place of the leads and plugs.
- KWC-DWG-001 to Rev P2; making sketches KWC-DWG-101, 102, 104 and 107, the overview, joints 5 and 6 and steps 3, 7 and 9 redrawn; build plan KWC-BLD-001 v0.2.
- Kitewright Lift and Kitewright Range: each frame's harness gains two pack input leads and two frame output leads of 8 AWG with AS150 plugs, soldered to the core's pads and tied to its strain-relief bar (Lift: KWL-DDR-003). The interface the frames see is otherwise unchanged.
- New question raised while applying the decision (KWC-DEC-001, O2, proposed, awaiting Amish): the 14S lithium-ion pack Kitewright Lift adopted charges to 58.8 V, 1.2 V under the 60 V rating of the power board and power modules.

> **Safety:** The core still switches up to 60 V and 200 A. With the leads in the frame harness, the polarity and the opposite-gender keying of the pack inputs and frame outputs are checked when the harness is soldered in (build plan step 9, hold point), before any pack is connected. Carbon dust from drilling or cutting the plate is a breathing hazard and carbon conducts: drill wet or under extraction and seal the cut edges so no fibres can bridge the power board.

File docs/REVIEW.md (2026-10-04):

# Review note: Kitewright Core

## Session 2026-09-30: scaffolded

### What was done

- Repository created from kit 1.6.0 at TRL 1, target TRL 2.
- `docs/01-problem.md` (KWC-PRB-001 v0.1): problem with cited evidence, users, environment, constraints, prior work, open questions.
- `docs/02-concept.md` (KWC-PRC-001 v0.1): how it works, components, patent design-arounds, shared blocks, safety.
- `docs/03-requirements.md` (KWC-REQ-001 v0.1): 11 proposed requirements.
- `README.md` with concept rationale, burning platform, where it could be used, and what sparked the idea.

### Next

- Run `/populate` to bring the repo to a strong TRL 2 with concept media.

## Session 2026-10-03: TRL 2 (populate), under Amish's pre-approval

Kit 1.7.0 installed. Amish's go for the batch (2026-10-03: "start with the first 14 repos from the list of 29 projects. I pre-approve the batch runs along with any recommendations you come up with. I also accept any cost overruns or variations from the assumed scope cost." and "Proceed with the remaining 15 scaffolds") counts as the TRL 2 approval, and every recommendation below is decided under it.

### What was done

- `docs/01-problem.md` (KWC-PRB-001 v0.2): open questions answered, co-design candidate named, budget worded as a value-engineering target, safety section.
- `docs/03-requirements.md` (KWC-REQ-001 v0.2): targets unchanged; rated payload, bus window and the R9 boundary defined; TRL 3 status per requirement.
- `docs/02-concept.md` (KWC-PRC-001 v0.2): how it works, components, key figures, design choices, safety section.
- Massing and media from `cad/src/concept_media.py`: `media/hero.png` (adult hand for scale), `cutaway.png`, `exploded.png` with BOM callouts, `flow.png` (power flow, estimates), `concept-blueprint.png/.pdf` (KWC-DWG-010), `model.glb` (coarse deflection, about 3 MB) and `viewer.html`.
- `bom/bom.csv`: 35 priced lines with suppliers.

### TRL 2 review items and how they were decided

Each item below was offered with options and a recommendation, and is recorded as decided in KWC-DDR-001 (D1 to D15): PX4 primary (D1); FMUv6X class controller (D2); 18 to 60 V bus (D3); one 5 kg, 100 W payload class (D4); plain rail with rear entry, front stops and pigtail (D5); two independent locking pins (D6, safety: conservative); core under the frame deck (D7); companion computer outside the core (D8); DroneCAN pack data (D9); radios per country (D10); three altitude bands (D11); DS-014 licence confirmed before purchase (D12); first co-design candidate to approach, not agreed (D13); logging and remote ID (D14); published hover-time model (D15).

### Safety concerns

- Lithium packs at up to 60 V and 200 A: bench supply first, anti-spark keyed connectors, fire plan.
- Falling payload: two pins, red bands, tug test before every flight.
- Propellers: the frames' safety stops apply; the core's safety switch gates arming.

## Session 2026-10-03: TRL 3 (advance and build plan), under Amish's pre-approval

### What was done

- `docs/04-calcs/01-sizing.md` and `sizing.py` (KWC-CAL-001 v0.1), `results.csv`.
- `cad/src/model.py`: parametric build123d model of the constructable core with 614 constructability checks, all passing; `cad/step/kitewright-core-assembly.step` and STL for the plate, lid, shoe, pin block and damping plate.
- `cad/src/sheets.py`: general arrangement KWC-DWG-001 Rev P1.
- `cad/src/build_plan_media.py`: overview, eight making sketches (KWC-DWG-101 to 108), seven joint close-ups and eleven step pictures.
- `docs/05-build-plan.md` (KWC-BLD-001 v0.1), `docs/06-design-decisions.md` (KWC-DEC-001 v0.1), `docs/decisions/0002-design-for-construction.md` (KWC-DDR-002).
- `cad/src/product_model.py` and render scenes exported to `/home/claude/renders/kitewright-core` (hero, exploded, detail, and the jobs file). Photoreal renders, captions and cards are made on Amish's Mac; the README already leads with `media/render-hero.png`.
- `project.yaml`: trl 3, trl_target 3, design_state constructable, trl_evidence listed. `budget_usd` unchanged.

### Results (KWC-CAL-001)

| ID | Status | Result |
| --- | --- | --- |
| R1 | Met on paper (licence and pinout to confirm) | DS-014 40-pin pigtail with bus and controller signals |
| R2 | Met on paper (estimate) | About 52 s with gloves, no tools |
| R3 | Met on paper | Factor 10.8 or more at 147 N; 221 N fore-aft on one pin alone |
| R4 | Met on paper (pin rating to confirm) | At most 5.6 A for 100 W |
| R5 | Met on paper | Hottest part about 75 °C at 45 °C ambient |
| R6 | Met on paper for the core | Sensors in range at 54 kPa; failsafes per band |
| R7 | Model ready; accuracy only at TRL 4 | 47 % (cold packs) and 70 % (ColdCell) of sea-level hover time at 5,000 m and -20 °C |
| R8 | Met by design | Lift 11, Range 10 of 16 outputs |
| R9 | Not met | 1.27 kg estimated |
| R10 | Met by design | Released PX4, parameters only |
| R11 | Under the value-engineering target | Value-engineering target: USD 5,000. Estimated cost of the constructable design: USD 3,940.60 (USD 1,059.40 under the target) |

### Requirements not met

- R9, core mass (below). R2 has a small margin and needs the gloved trial at TRL 4.

### Decisions for Amish

**R9, core mass.** State: the constructable core is estimated at 1.27 kg against R9, 274 g over. Cause: the plate, rails, pin blocks and lid are sized for making from aluminium sheet and bar (strength factors of 10 to 99), and the four 8 AWG power leads with their AS150 plugs (124 g) sit inside the core.

| Option | What changes | Effect on R9 | Cost | Mass |
| --- | --- | --- | --- | --- |
| A | Lighter structure: 2 mm carbon fibre plate, 1.5 mm lid walls, pockets milled in the rail bars | Still not met (about 1.12 kg) | About USD 60 more | -157 g |
| B | A, plus the pack and frame leads and AS150 plugs moved to each frame's harness; the core keeps solder pads and a strain-relief bar | Met (about 0.99 kg) | About USD 60 more on the core; USD 60 of leads move to the frames | -281 g |
| C | Keep the design as drawn | Not met (1.27 kg) | None | None |

**Recommendation: B.** It meets R9 with a small margin, keeps every strength factor above 5, and the lead lengths were frame-specific anyway; it needs Kitewright Lift and Kitewright Range to own their power leads. Listed in KWC-DEC-001 as O1, "Proposed, awaiting Amish".

### Decisions made under the pre-approval

- KWC-DDR-001, D1 to D15 (TRL 2 review), and KWC-DDR-002, C1 to C10 (design for construction), all dated 2026-10-03 and indexed in KWC-DEC-001.

### Build plan findings (design changes made for construction, KWC-DDR-002)

- C1 plain rail of spacer bars and taped lips; C2 two plungers in pin blocks; C3 front stops clamped by the rail screws; C4 DS-014 pigtail through a plate slot and a shoe notch; C5 flush clinch nuts under the plate; C6 core hung under the frame deck on spacers, lid through a deck opening; C7 damped controller plate above the power board; C8 printed lid with gasketed flange; C9 leads out through grommets, plugs soldered last; C10 removable GNSS mast.
- The shoe's 0.3 mm running gap depends on stock thicknesses and the tape; the first check is a feeler-gauge check along the rail.

### Appearance model

- `cad/src/product_model.py` uses the model's components unchanged; there are no appearance deviations from `model.py`. The hero places an adult hand beside the core on the bench, to the right of it in view, never in front.

### Safety concerns

- Lithium power path (60 V, 200 A peak): build plan safety stops 1 and 2; inputs and outputs keyed by opposite-gender plugs.
- Payload retention: two independent pins (D6, conservative). A vibration and pull test on the built mount could justify one pin later.
- The proof-load check (15 kg) is done with the core on a fixed stand and nobody beneath.
- Radio band and power must be legal at each site; flights only under the site partner's permissions.

### Cross-repo actions (sibling repos not edited)

- **Kitewright Lift and Kitewright Range:** provide a lower deck with four M4 hard points on a 220 x 130 mm pattern, a 200 x 112 mm opening for the lid, and at least 70 mm clear above the deck for the lid and 240 mm for the GNSS mast (or a frame position for the GNSS on a longer cable); carry the core's mass of about 1.27 kg (0.99 kg if O1 goes with B); accept AS150 frame outputs on an 18 to 60 V bus; keep the payload's neck zone (88 mm wide, 30 mm below the lips) and the area behind the rail clear for rear entry of the shoe. If O1 goes with B, each frame supplies its own pack and output leads.
- **Kitewright Range:** fuselage pod interior at least 150 mm wide at the core position; 10 of the controller's 16 outputs are used.
- **ColdCell:** report temperature and charge over DroneCAN; AS150 pack connector; pack voltage within 18 to 60 V; block charging when cold (the core does not).
- **AvalancheScout, LakeWatch and other payloads:** carry a 184 x 128 x 5 mm shoe to KWC-DWG-106, stay within 5 kg and 100 W, and put the DS-014 socket where the plug reaches in front of the shoe's notch.
- **AltiRig:** supply the hover-thrust factors used in the altitude parameter sets (KWC-CAL-001, Table 6).

### Recommended next step

Amish decides O1 (R9). The design is ready for TRL 4 (build and bench checks of section 5 of the build plan) once the DS-014 licence and pinout are confirmed; that is a recommendation, not started.

## 2026-10-03: photoreal renders

Rendered with Blender Cycles on Amish's Mac from `cad/src/product_model.py`; captioned with `.kit/photo_caption.py`; `media/card.png` and `media/social-preview.png` made with `.kit/cards.py`. Views: hero, exploded, detail. image_qc passes and `render.py --check` has no FAIL.

## 2026-10-03: Amish's requirement decisions carried out

Amish Chadha (owner) on 2026-10-03: "i agree with all the 46 recommendations you provided. please proceed." His round 2 decision for this repo is item 33B: lighter structure and the power leads moved out of the core into the frames. It is recorded in KWC-DDR-003 (`docs/decisions/0003-r9-core-mass.md`) and in the register (`docs/06-design-decisions.md`, O1 moved to Decisions made).

### Changes made

- **Model** (`cad/src/model.py`; 720 constructability checks, all passing, up from 614). New checks cover the strain-relief bar, the frame harness drawn as context (it reaches the pads, the grommets and the bar, and overlaps nothing), a flush underside wherever the shoe runs, the metal left by the pockets and the land under each countersink. STEP and STL regenerated.
  - Core plate: 2 mm carbon fibre, CNC-cut, in place of 2 mm 5052 aluminium. The 14 clinch nuts cannot go into carbon, so 16 M3 holes are countersunk from below; countersunk screws set with thread-locker carry the standoffs (now female-female) and act as the lid's six studs (nylon-insert nuts on the flange).
  - Rail spacer bars: three 3.6 mm windows between the screws. Rail lips: three 1.8 mm pockets underneath. Both are clear-anodised, as are the front stops, corner spacers and standoffs, because they touch the carbon.
  - Pin blocks from 30 x 12 mm bar (was 15 mm; M4 x 30 screws); corner spacers 12 mm OD (was 16 mm); lid walls and top 1.5 mm (was 2 mm).
  - Power leads and AS150 plugs removed from the core. The frame's own harness comes in through the existing grommets and is soldered to the board's pads. A new strain-relief bar (G10, 60 x 8 x 2 mm, on two 12 mm standoffs behind the lid) takes any pull on the leads.
- **BOM** (`bom/bom.csv`): lines 1, 2, 3, 4, 6, 7, 10, 14, 20, 21 and 27 changed, each with a price basis. Line 20 is now the countersunk fixings and line 21 the strain-relief bar (the USD 60 of leads and plugs move to the frames).
- **Calculations** (KWC-CAL-001 v0.2): sections A, H, I and the results updated; new checks A2 (the lip at its pocket floor), A4 (the carbon side beam with the windowed bar) and A8 (carbon bearing).
- **Requirements** (KWC-REQ-001 v0.3): R3, R8, R9 and R11 status updated, and the R9 definition now excludes the frame's harness. No targets changed; 33B does not restate a requirement.
- **Build plan** (KWC-BLD-001 v0.2): sections 1, 2, 3.1, 3.2, 3.3, 3.4, 3.5 and 3.7, a new section 3.9 (strain-relief bar, Figure 10; later figures renumbered), Table 2, steps 1 to 4, 7, 9 and 11, the first checks, safety stop 2, and tools.

### New result per requirement

| ID | Before | Now | Target |
| --- | --- | --- | --- |
| R9 | 1.27 kg, not met | 0.99 kg, met on paper (10 g margin; bought-part masses to confirm, T9) | 1.0 kg or less |
| R3 | Factors 10.8 or more | Factors 8.3 or more: lips 19 x at the pocket floor, carbon side beam 8.3 x, carbon bearing 14 x, screws 69 x, one pin 36 x | 3 x static, 1.5 x at 2 g |
| R11 | USD 3,940.60 | Value-engineering target: USD 5,000. Estimated cost of the constructable design: USD 3,946.80 (USD 1,053.20 under the target) | USD 5,000 |
| R8 | Met by design | Met by design for firmware and fixing; a core moved between frames now needs a harness change (O2, below) | Parameter changes only |

All other requirements are unchanged. Mass breakdown: carbon plate -81 g, rail windows and pockets -44 g, pin blocks and corner spacers -20 g, lid -24 g, leads and plugs -124 g, strain-relief bar and fixings +9 g; 284 g lighter in all. Cost: about USD 58 more for the structure, USD 8 for the strain-relief bar, USD 0.80 less in fixings and USD 60 of leads out: USD 6.20 more in all.

### Pictures changed

General arrangement KWC-DWG-001 to Rev P2. Making sketches KWC-DWG-101, 102, 104, 105 and 107 to Rev P2, and KWC-DWG-109 (strain-relief bar) new. The other sketches were redrawn unchanged. Also redrawn: the overview, joints 1, 2, 5, 6 and 7, all eleven step pictures (step 3 is now the power board alone, step 9 the strain-relief bar, and step 11 adds the frame's harness), and the concept media (hero, cutaway, exploded, blueprint, flow, model.glb). The appearance model (`cad/src/product_model.py`) shows the carbon plate and the strain-relief bar; render scenes were exported again. The photoreal renders, captions and cards in `media/` still show the aluminium plate with leads and need a re-run on Amish's Mac.

### New decision for Amish

**O2, R8 common core and the frame harness.** State: since 33B the frame's power leads are soldered to the core's board pads. A core moved between Lift and Range therefore needs its harness changed: lid off, four 8 AWG leads desoldered and the other frame's soldered on. R8 reads "parameter changes only".

| Option | What changes | Effect | Cost and mass |
| --- | --- | --- | --- |
| A | Accept a bench harness change (about 30 min, lid off) and restate R8 as "same core flies Lift and Range with parameter changes and a change of the frame's power harness at the board" | R8 met as restated; R9 stays met | None |
| B | Four M4 studs on the board's pads, with ring lugs on the frame leads: a nut-driver swap, no soldering | R8 closer to its wording; R9 missed by about 2 g | About 12 g and USD 15 more |
| C | AS150 plugs back on short core pigtails | R8 met as written; R9 not met (about 1.06 kg) | About 70 g more |

**Recommendation: A.** The R8 check at TRL 4 is a single bench swap by the builder, soldering 8 AWG is already in the build plan, and R9 stays met. Listed as O2 in KWC-DEC-001, "Proposed, awaiting Amish".

### Safety

- Carbon dust when cutting or filing the plate: wet or under extraction, with a mask.
- Galvanic corrosion between aluminium and carbon: every aluminium part that touches the plate is anodised, and the plate's edges are sealed.
- The frame's harness is soldered inside the lid. Safety stop 2 now checks the harness's keyed, labelled AS150 plugs and their polarity before any pack is connected.
- The countersinks leave 0.4 mm of carbon under each M3 head (T7). If the heads pull through, the fallback is bonded flush inserts.

### Cross-repo actions (not edited here)

- **Kitewright Lift and Kitewright Range** (Core decision 33B): each frame supplies its own power harness: two pack leads and two output leads in 8 AWG, with AS150 plugs (inputs and outputs of opposite gender), labelled, and long enough to pass through the core's two rear grommets (20 mm holes, 13 mm each side of the centre line, 18 mm above the plate) to the board's pads, about 20 mm inside the lid's rear wall. Mass about 124 g and cost about USD 60 per frame. Core mass for frame sizing is now about 0.99 kg.
- **Kitewright Lift and Kitewright Range:** the core's corner spacers are now 12 mm OD (were 16 mm); the 220 x 130 mm M4 pattern and the 200 x 112 mm deck opening are unchanged. Keep 1 mm or more clear of the strain-relief bar, which sits 91 to 99 mm behind the core's centre, up to 14 mm above the plate.

## 2026-10-04: Amish's round-3 decisions carried out

Amish Chadha (owner) on 2026-10-04: "For round 3, I agree with all your proposed recommendations". For Kitewright Core that is item 7A (register item O2, R8) and its share of the Kitewright family reconciliation (8A, 9A and 10A), which also touched Kitewright Lift, Kitewright Range, ColdCell, AvalancheScout and LakeWatch. Recorded in `docs/decisions/0004-r8-harness-change.md` (KWC-DDR-004) and the register (`docs/06-design-decisions.md` v0.3). Nothing was committed or pushed.

### Changes made

- **7A, R8 restated** (`docs/03-requirements.md` v0.4): "Same core flies Lift and Range with parameter changes and a change of the frame's power harness at the board." The bench harness change (lid off, four 8 AWG leads resoldered, about 30 min) is accepted. New result: **R8 met by design as restated.** No hardware, cost or mass change; R9 stays 0.99 kg (met on paper) and R11 USD 3,946.80 (USD 1,053.20 under the USD 5,000 target).
- **Build plan** (`docs/05-build-plan.md`): step 11 now says how a core moves to the other frame.
- **10A, interface reconciliation:** the Core's drawings (KWC-DWG-001 Rev P2, KWC-DWG-106) are the reference for the one mounting envelope that Lift and Range now both carry; both frames model the Core from these figures (`cad/src/core_envelope.py` in each). No change to the Core itself, so the model, drawings and render scenes are unchanged.

### Kitewright interface table

The same table stands in the review notes of Kitewright Core, Kitewright Lift, Kitewright Range, ColdCell, AvalancheScout and LakeWatch (Amish's decision 10A, 2026-10-04). The Core's drawings are the reference for the mounting envelope.

| Interface | Family figure | Source |
| --- | --- | --- |
| Power connector | AS150 on every pack lead and on each frame's power harness (two pack inputs, two frame outputs, opposite genders); no XT60 or XT90 on the bus | Decision 10A; KWC-DDR-001, D3 |
| Core mounting envelope and hole pattern | Core plate 240 x 150 x 2 mm hung under the frame's lower deck on four 12 mm OD x 8 mm corner spacers; four M4 holes on a 220 x 130 mm pattern; a 200 x 112 mm opening in the deck for the lid; lid 168 x 92 mm, its top 55 mm above the deck's underside (GNSS mast boss 69 mm); where a frame has no 240 mm clear above the lid, the antennas and GNSS receiver go to frame positions on extension cables; rail, pin blocks and pin knobs to 47 mm below the plate top; payload shoe 184 x 128 x 5 mm, payload neck 88 mm wide from the shoe to 30 mm below the rail lips | KWC-DWG-001 Rev P2, KWC-DWG-106 |
| Bus voltage | 18 to 60 V at the Core's pack inputs. Lift: 14S lithium-ion, 42.0 to 58.8 V (50.4 V nominal). Range: 6S lithium-ion, 18.0 to 25.2 V (21.6 V nominal) | KWC-DDR-001, D3 |
| Pack size and mass | Lift: two ColdCell 14S3P lithium-ion packs, 410 x 94 x 94 mm, 4.46 kg and 680 Wh each (CCL-DWG-002). Range: two 6S3P lithium-ion packs of 5.0 Ah cells, 138 x 75 x 82 mm, 1.40 kg and 324 Wh each (Range's figure; ColdCell has not yet drawn this pack) | Decision 8A; CCL-CAL-001 K; KWR-CAL-001 |
| Core mass | 0.99 kg: avionics, radios, GNSS, rail and locking pins; packs, payload shoe and the frame's harness excluded | Core R9; KWC-DDR-003 |

What the frames gave the Core when they took this envelope (nothing in the Core changes): Lift hangs the Core under its bottom hub plate with 63 mm from the deck's underside to its top hub plate, which is drilled over the lid's mast boss, SMA bulkheads and switch; Range hangs it under its fuselage floor at the centre of gravity, the fuselage widened to 150 mm inside. Both take the Core's GNSS receiver and antennas to frame positions on extension cables, as the table allows. The Core asked for 70 mm clear above the deck; its own drawing needs 55 mm for the lid and 69 mm at the mast boss.

### Pictures changed

None: no geometry changed in this repo.

### Open decisions

None. Nothing in carrying out 7A or the reconciliation needs Amish here.

### Safety

- A harness change means soldering 8 AWG leads inside the lid: every pack disconnected, a 100 W iron, and safety stop 2 (polarity at the AS150 plugs with a meter) repeated before the first pack goes on.

### Cross-repo actions

- None outstanding from this repo: Lift, Range, ColdCell, AvalancheScout and LakeWatch were brought to the table in the same reconciliation.

### Recommended next step

Unchanged: the design is ready for TRL 4 (build and the bench checks of section 5 of the build plan) once the DS-014 licence and pinout are confirmed; a recommendation, not started.

## 2026-10-04: photoreal renders redone after the round-2 and round-3 decisions

Views: hero, exploded, detail; cards regenerated; image_qc passes and `render.py --check` has no FAIL.

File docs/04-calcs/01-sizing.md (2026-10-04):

---
doc_id: KWC-CAL-001
title: Kitewright Core sizing calculations
project: Kitewright Core
doc_type: Calculation
version: "0.2"
status: Draft
date: '2026-10-03'
author: Amish Chadha
license: CERN-OHL-S-2.0
revisions:
- version: "0.1"
  date: '2026-10-03'
  author: Amish Chadha
  change: "First issue for TRL 3 on the constructable design (KWC-DDR-002): mount strength, payload swap, payload power, heat, altitude, hover-time model, common core, mass and cost"
- version: "0.2"
  date: '2026-10-03'
  author: Amish Chadha
  change: "Decision 33B carried out (KWC-DDR-003): carbon plate, pocketed rail bars, lighter pin blocks, corner spacers and lid, power leads moved to the frames; R3, R8, R9 and R11 recomputed; R9 now met on paper at 0.99 kg"
---

# Kitewright Core sizing calculations

On paper the constructable core, lightened under Amish's decision 33B of 2026-10-03 ("i agree with all the 46 recommendations you provided. please proceed."), meets all eleven requirements, with one new point on R8 set out for Amish (open decision O2). The plain rail and two locking pins carry the 147 N vertical design load with factors of 8 or more on every part, a gloved payload swap takes about 52 s with no tools, 100 W reaches the payload at no more than 5.6 A, and the hottest avionics part stays near 75 °C at 45 °C ambient. The hover-time model explains the scaffold's 47 % figure: at 5,000 m and -20 °C an aircraft keeps 77.5 % of its sea-level hover time from air density alone, and unheated packs that give 60 % of their capacity bring it to 46.5 %; ColdCell packs kept warm raise it to 70.0 %. The core's estimated mass is 0.99 kg, 10 g inside R9's 1.0 kg, after the carbon plate, the pocketed rail bars and the move of the power leads to the frames. The estimated cost of USD 3,946.80, with ground station and spares, is USD 1,053.20 under the USD 5,000 value-engineering target. Every number here is printed by `docs/04-calcs/sizing.py`; the tag in brackets, for example [A3], is the line of that script's output that carries it.

> **Safety:** These are first-principles estimates for a paper proof of concept. They do not show that the payload mount, the lithium packs, the power wiring or the aircraft is safe. The mount must be proof-loaded and the locking pins pull-tested, and the power board must be checked on a current-limited bench supply, before any pack is connected or any payload is flown. See KWC-PRC-001, Safety.

## Scope and method

The note checks every requirement in KWC-REQ-001 v0.2 against the design in KWC-PRC-001 v0.2 and the parametric model `cad/src/model.py`. The script imports the model's parameters and part volumes, so the plate, rails, shoe, pin blocks and lid used here are the ones in the STEP file, drawing KWC-DWG-001 and the build plan. It also reads `bom/bom.csv` and `budget_usd` in `project.yaml`. Run it from the repo root with `python docs/04-calcs/sizing.py`; it also writes `docs/04-calcs/results.csv`.

## Assumptions

*Table 1. Main assumptions.*

| Area | Assumption | Basis |
| --- | --- | --- |
| Rated payload | 5 kg on the mount, one payload class for version 1 (KWC-DDR-001, D4) | Kitewright Lift's sea-level payload |
| Load cases | Static 3 x 5 kg; drop 1.5 x 5 kg at 2 g (both 147 N, R3); fore-aft 1.5 x 5 kg at 3 g (221 N) on one pin alone; side 1.5 x 5 kg at 1 g with the payload's centre of mass 80 mm below the shoe | R3 and screening values |
| Materials | 6061-T6 yield 276 MPa; 2 mm woven carbon plate: design allowable 250 MPa in bending and 200 MPa in bearing (typical strength 500 to 600 MPa, halved for holes, cold and moisture); hardened plunger pin 400 MPa in shear (conservative); M4 A2-70 screws at 0.8 x proof (3,161 N) | Handbook values; maker data for the plate class |
| Swap | Seven hand actions totalling 35 s bare-handed; gloves multiply by 1.5 | Estimate |
| Bus | 18 V (6S Li-ion at 3.0 V a cell) to 60 V; 100 W payload; pigtail 0.3 m of 20 AWG, two pins each way; payload switch limit 8 A | KWC-DDR-001, D3 |
| Heat | Lid surface 0.0477 m² (top and sides); 10 W/m²K in still air, 25 W/m²K in hover; 10 K allowance for sun on the frame body around the lid; 10 K from lid air to the hottest part; parts rated -40 to +85 °C | Handbook ranges; maker ratings of the part classes |
| Dissipation | Flight controller 2.5 W, telemetry 1 W idle and 2 W in flight, receiver 0.3 W, 5.3 V supplies 1.1 W, payload switch 0.47 W, bus conduction 4 W at 100 A through 0.4 mΩ | Estimates; 100 A is Kitewright Lift's hover estimate at 44 V |
| Atmosphere | International Standard Atmosphere | ISA |
| Hover model | Hover power proportional to 1/√(density) for the same mass and rotors; unheated Li-ion gives 60 % of capacity at -20 °C; ColdCell packs give 95 % and spend 5 % on their heater | Momentum theory; typical cell data |
| Mass | Made parts from model volumes (aluminium 2.70, carbon plate 1.55, ASA 1.07, G10 1.85, UHMW-PE 0.94 g/cm³); bought parts from catalogue class values (Table 8) | Estimates, to confirm when bought |

## A. Mount strength (R3)

The vertical design load is 147 N in both R3 cases [A1]. The shoe overlaps each lip by 19 mm along 184 mm; the lip bends about the spacer bar's inner edge with a 10.5 mm lever, giving 2.8 MPa, a factor of 99 on yield [A2]. The lightening pockets under the lips leave a 1.2 mm floor that stops 2 mm short of the spacer bar; at the pocket's edge, taking the pocket along the whole shoe length, the lip reaches 14.2 MPa, a factor of 19 [A2]. The ten M4 screws that hold the lips see at most 46 N each with prying, a factor of 69 [A3]. Between the frame bolts, 220 mm apart, the carbon plate's edge strip, the windowed spacer bar and the pocketed lip, taken as three separate beams, reach 30 MPa, a factor of 8.3 on the carbon plate's 250 MPa allowable [A4]. With one pin alone holding the 221 N fore-aft case, its block's two M4 screws bear on the 2 mm carbon at 13.8 MPa, a factor of 14 [A8].

Fore and aft, the shoe is held by the front stops one way and by the locking pins both ways. The 221 N fore-aft case on ONE pin gives 11.2 MPa of shear in the 5 mm pin and 8.8 MPa of bearing in the shoe [A5]; forward load into the two front stops gives 1.2 MPa [A6]. A 1 g side load with the payload's centre of mass 80 mm down puts 54 N on each lip [A7]. Every factor is still large after decision 33B's lightening, because the parts were sized for making and handling, not for strength. That margin is why two independent pins cost little: either pin alone holds the payload. The carbon plate needs two cautions that the numbers do not show: aluminium touching it is anodised so the pair cannot corrode in wet snow, and the M4 nuts on it sit on washers and are tightened to about 2 N·m so they do not crush the laminate.

## B. Payload swap (R2)

*Table 2. Swap sequence [B1].*

| Action | Time, bare-handed (s) |
| --- | --- |
| Unplug the DS-014 plug | 6 |
| Pull and twist both locking pins to their rest | 5 |
| Slide the payload out to the rear | 4 |
| Slide the next payload in to the front stops | 5 |
| Twist both pins back; they snap into the shoe | 3 |
| Plug the DS-014 plug and close its latch | 8 |
| Check both pins show no red band; tug the payload | 4 |
| Total | 35 |

With gloves the swap takes about 52 s and needs no tools. The margin to R2's figure is small, so a timed gloved trial at TRL 4 is the real check.

## C. Payload power (R4)

*Table 3. Payload current at the end of discharge [C1].*

| Bus | Voltage (V) | Current for 100 W (A) | Pigtail drop (mV) |
| --- | --- | --- | --- |
| 6S Li-ion, 3.0 V a cell | 18.0 | 5.56 | 56 |
| 12S Li-ion | 36.0 | 2.78 | 28 |
| 16S LiFePO4, 2.8 V a cell | 44.8 | 2.23 | 22 |

The 8 A payload switch covers the worst case with a 1.44 x margin [C2]. The current each DS-014 battery pin may carry is to be confirmed from the published standard and the chosen connector; two pins each way at 3 A would cover the 6S case.

## D. Heat (R5)

The lid encloses 4.9 W on the ground and 10.4 W in Kitewright Lift's hover, where 4 W comes from the 100 A bus current [D1]. On a 45 °C day, with 10 K allowed for sun on the frame body, the lid air reaches 65.3 °C on the ground and 63.7 °C in hover, and the hottest part about 75 °C, 10 K inside the 85 °C rating [D2]. Cold-soaked to -20 °C, every part boots within its -40 °C rating, and once running the lid air settles near -10 °C [D3]. The optional companion computer sits outside the lid (KWC-DDR-001, D8), so its 5 W does not count here.

## E. Altitude (R6)

*Table 4. International Standard Atmosphere [E1].*

| Altitude (m) | Temperature (°C) | Pressure (kPa) | Density (kg/m³) | Share of sea-level density |
| --- | --- | --- | --- | --- |
| 0 | 15.0 | 101.3 | 1.225 | 100 % |
| 3,000 | -4.5 | 70.1 | 0.909 | 74 % |
| 5,000 | -17.5 | 54.0 | 0.736 | 60 % |
| 6,000 | -24.0 | 47.2 | 0.660 | 54 % |

At 5,000 m and -20 °C the density is 0.743 kg/m³, and the barometer must read down to 54 kPa; flight-controller barometers of this class read 30 to 110 kPa [E2]. The core's share of R6 is sensors in range and failsafes set for each band (Table 6). Whether a frame has the thrust to stay in control is a frame property, checked in Kitewright Lift and Kitewright Range with AltiRig data.

*Table 6. Altitude parameter sets: what each band changes (released PX4, parameters only).*

| Setting | Sea level band (0 to 1,500 m) | 3,000 m band (1,500 to 4,000 m) | 5,000 m band (4,000 to 6,000 m) |
| --- | --- | --- | --- |
| Hover thrust estimate | From the frame's sea-level hover test | Sea-level value x 1.16 | Sea-level value x 1.29 |
| Low-battery warning and return | 30 % and 20 % | 35 % and 25 % | 40 % and 30 % |
| Return altitude above launch | 30 m | 50 m | 80 m (terrain) |
| Link-loss action | Return after 5 s | Return after 5 s | Return after 3 s |
| Geofence | Set per site, 1,000 m radius by default | As sea level | As sea level, 120 m ceiling above launch |
| Pack temperature before arming | ColdCell reports at least 10 °C | As sea level | As sea level |

The hover-thrust factors are 1/√(density share) from Table 4; the battery thresholds are deliberately higher at altitude because a return through thin air takes more energy. All values are starting points to be tuned on AltiRig and in flight.

## F. Hover-time model (R7)

For the same aircraft and mass, hover power scales with 1/√(density), so hover time at 5,000 m is 0.775 of sea level from air alone [F1]. Unheated packs that give 60 % of their capacity at -20 °C bring that to 46.5 %, which is the scaffold's 47 % estimate [F2]. ColdCell packs kept warm, giving 95 % of their capacity and spending 5 % on their heater, bring it to 70.0 % [F3]. The model is:

hover time = usable pack energy x (1 - heater share) x efficiency / hover power, with hover power = (m g)^1.5 / (figure of merit x √(2 x density x rotor disc area)).

It leaves out the change in motor and propeller efficiency at the higher rotor speeds of thin air; AltiRig measures that. R7 asks that the model predict measured hover time within 15 %, which only TRL 4 flights can show.

## G. Common core (R8, R10, R1)

*Table 7. Outputs needed on the flight controller [G1].*

| Frame | Outputs needed | Available |
| --- | --- | --- |
| Lift, eight motors, plus three payload channels | 11 | 16 |
| Lift, six motors, plus three payload channels | 9 | 16 |
| Range, four lift motors, pusher and five servos | 10 | 16 |

One core, one frame pattern and one payload interface serve both frames with parameter changes only (R8). Released PX4 (v1.15 or later) runs multirotor and standard VTOL frames, DroneCAN battery reporting and MAVLink payload protocols without source changes (R10). The DS-014 pigtail carries the battery, Ethernet, CAN, UART and trigger lines named in the standard (R1); the exact pinout and licence terms are confirmed from the published standard before the connector is bought.

## H. Mass (R9)

*Table 8. Core mass after decision 33B [H1, H2].*

| Part | Mass (g) | Source |
| --- | --- | --- |
| Core plate, 2 mm carbon | 109 | Model volume |
| Rail spacer bars (windowed), lips (pocketed) and wear tape | 118 | Model volume |
| Front stops, pin blocks (12 mm), jam nuts, corner spacers (12 mm) | 77 | Model volume |
| Lid, 1.5 mm walls | 90 | Model volume |
| Damping plate and strain-relief bar | 30 | Model volume |
| Flight controller | 100 | Catalogue class |
| Power board, power modules | 105 | Catalogue class |
| Radio, receiver, antennas and bulkheads | 91 | Catalogue class |
| GNSS receiver and mast | 45 | Catalogue class |
| Locking pins (2) | 50 | Catalogue class |
| DS-014 pigtail, harness, switch, grommets, gasket | 110 | Catalogue class |
| Dampers, standoffs, countersunk fixings, strain-relief standoffs and ties, fasteners | 64 | Catalogue class |
| Total (rows rounded) | 989 | |

The core weighs about 0.99 kg without the payload shoe (310 g, counted with each payload) and without the optional companion computer (60 g, outside the lid) [H2]. That is 10 g inside R9's 1.0 kg [H3], and 284 g lighter than the 1.27 kg core drawn before decision 33B [H4]. The saving comes from the 2 mm carbon fibre plate (81 g), windows in the spacer bars and pockets under the lips (44 g), 12 mm pin blocks and 12 mm corner spacers (20 g), 1.5 mm lid walls (24 g), and the four 8 AWG power leads with their AS150 plugs (124 g), which now belong to each frame's harness; the strain-relief bar and the countersunk fixings that replace the clinch nuts add back about 9 g. The frames carry the leads instead, so the aircraft's mass is unchanged overall [H5]. The 10 g margin is thin against catalogue-class masses for the bought parts, so weighing the bought parts when they arrive (register, T9) decides it.

## I. Cost (R11)

The bill of materials comes to USD 1,766.80 for the airborne core, USD 1,620.00 for the ground station and USD 560.00 for spares [I1]. Decision 33B adds about USD 58 for the lighter structure (carbon plate USD 40, milling and anodising the rail bars USD 20, USD 1 less filament), USD 8 for the strain-relief bar and USD 0.80 less in fixings, and removes the USD 60 of leads and plugs that the frames now supply: USD 6.20 more in all. Value-engineering target: USD 5,000. Estimated cost of the constructable design: USD 3,946.80 (USD 1,053.20 under the target) [I2].

## L. Results against every requirement

*Table 9. Results (also in `docs/04-calcs/results.csv`).*

| ID | Result | Status |
| --- | --- | --- |
| R1 | DS-014 40-pin connector on a 0.3 m pigtail; signals from the flight controller and bus | Met on paper (licence and pinout to confirm) |
| R2 | About 52 s with gloves, no tools; pin state shown by a red band | Met on paper (estimate) |
| R3 | Vertical 147 N: lips 19 x at the pockets, screws 69 x, carbon side beam 8.3 x; fore-aft 221 N on one pin 36 x, carbon bearing 14 x | Met on paper |
| R4 | 100 W needs at most 5.6 A (6S at 18 V); switch limit 8 A | Met on paper (pin rating to confirm) |
| R5 | Hottest part about 75 °C at 45 °C ambient; cold boot at -20 °C within the -40 °C rating | Met on paper |
| R6 | Sensors in range at 54 kPa; failsafes set per altitude band | Met on paper for the core; flight check needs a frame |
| R7 | Model published: 47 % (cold packs) and 70 % (ColdCell) of sea-level hover time at 5,000 m and -20 °C | Model ready; accuracy shown only at TRL 4 |
| R8 | One core and one interface; Lift needs 11 of 16 outputs, Range 10; moving the core between frames now also changes the frame's soldered power harness | Met by design for firmware and fixing; harness change open (O2, `docs/REVIEW.md`) |
| R9 | 0.99 kg estimated (decision 33B) | Met on paper, 10 g margin; bought-part masses to confirm |
| R10 | Released PX4, parameters and stock modules only; ColdCell reports over DroneCAN | Met by design |
| R11 | USD 3,946.80 including ground station and spares | Under the value-engineering target by USD 1,053.20 |

## Checks against earlier figures

- The scaffold's estimate of 47 % hover time at 5,000 m and -20 °C is reproduced (46.5 %) and traced to unheated packs; with ColdCell the model gives 70 %.
- R9 was written before the core had a constructable structure; the constructable design as first drawn missed it at 1.27 kg (version 0.1). Under decision 33B it meets it at 0.99 kg, within 1 % of the 0.99 kg estimated for option B in version 0.1.

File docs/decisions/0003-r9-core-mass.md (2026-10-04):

---
doc_id: KWC-DDR-003
title: Kitewright Core R9 core mass, lighter structure and power leads in the frames
project: Kitewright Core
doc_type: Design decision record
version: "0.1"
status: Draft
date: '2026-10-03'
author: Amish Chadha
license: CERN-OHL-S-2.0
revisions:
- version: "0.1"
  date: '2026-10-03'
  author: Amish Chadha
  change: Amish's decision 33B (option B of register item O1) recorded and carried out
---

# 0003: R9 core mass: lighter structure, power leads moved to the frames

- **Date:** 2026-10-03
- **Status:** accepted. Decided by Amish Chadha on 2026-10-03, round 2 item 33B: "i agree with all the 46 recommendations you provided. please proceed."

## Context

The constructable core of KWC-DDR-002 was estimated at 1.27 kg against R9's 1.0 kg (KWC-CAL-001 v0.1, section H). Its plate, rails, pin blocks and lid were sized for making from aluminium sheet and bar, with strength factors of 10 to 99, and the four 8 AWG power leads with their AS150 plugs (124 g) sat inside the core. The item was put to Amish as register item O1 with three options.

## Options considered

| Option | What changes | Effect on R9 | Cost |
| --- | --- | --- | --- |
| A | Lighter structure: carbon fibre plate, 1.5 mm lid walls, pocketed rail bars | Still not met (about 1.12 kg) | About USD 60 more |
| B | A, plus the pack and frame leads and AS150 plugs moved to each frame's harness; the core keeps solder pads and a strain-relief bar | Met (about 0.99 kg) | About USD 60 more on the core; USD 60 of leads move to the frames |
| C | Keep the design as drawn | Not met (1.27 kg) | None |

## Decision

Option B, as recommended. Carried out as follows (model `cad/src/model.py`, 720 constructability checks, all passing):

| # | Part | Was | Now | Mass saved |
| --- | --- | --- | --- | --- |
| L1 | Core plate | 2 mm 5052 aluminium with 14 pressed clinch nuts | 2 mm carbon fibre plate, CNC-cut; 16 M3 holes countersunk from below; M3 countersunk screws set from below with thread-locker carry the standoffs and act as the lid's studs (nylon-insert nuts on the flange). Clinch nuts cannot be pressed into carbon | 81 g |
| L2 | Rail spacer bars | Solid 10 x 6 mm bar | Three 3.6 mm windows between the screws, 1.2 mm flanges left; clear-anodised | 24 g |
| L3 | Rail lips | Solid 30 x 3 mm bar | Three pockets 1.8 mm deep under each lip between the screws, stopping 2 mm short of the spacer bar | 20 g |
| L4 | Pin blocks | 30 x 15 mm bar | 30 x 12 mm bar (12 mm of M10 x 1 thread); M4 x 30 screws | 12 g |
| L5 | Corner spacers | 16 mm OD | 12 mm OD, anodised | 8 g |
| L6 | Lid | 2 mm walls and top | 1.5 mm walls and top | 24 g |
| L7 | Power leads and AS150 plugs | Four 8 AWG leads and four AS150 halves in the core (BOM line 21, USD 60) | Supplied by each frame's harness (Kitewright Lift and Range); they enter through the existing grommets and solder to the board's pads | 124 g |
| L8 | Strain-relief bar (new, BOM line 21) | None | 60 x 8 x 2 mm G10 bar on two 12 mm standoffs behind the lid; the frame's leads are tied to it (KWC-DWG-109) | -9 g with the fixings |

L4 and L5 go a little beyond the three items named in option A. They were needed to reach option B's 0.99 kg in the model, and they are part of the same lighter structure.

## Results (KWC-CAL-001 v0.2)

- **R9:** 0.99 kg estimated, 10 g inside 1.0 kg. Met on paper; the margin is thin against catalogue-class bought-part masses (register, T9).
- **R3:** still met. Lips 19 x at the pocket floor, screws 69 x, carbon side beam 8.3 x on a 250 MPa allowable, carbon bearing 14 x at the pin block screws.
- **R11:** USD 3,946.80, USD 6.20 more than before (structure about USD 58, strain-relief bar USD 8, fixings USD 0.80 less, leads USD 60 moved out). Value-engineering target: USD 5,000. Estimated cost of the constructable design: USD 3,946.80 (USD 1,053.20 under the target).
- **R8:** firmware and fixing unchanged, but a core moved between Lift and Range now needs the frame's soldered harness changed. Put to Amish as register item O2.

## Consequences

- Kitewright Lift and Kitewright Range supply their own pack and output leads (8 AWG) with AS150 plugs, inputs and outputs of opposite gender, long enough to reach the board's pads through the core's rear grommets (cross-repo; not edited here).
- Galvanic corrosion: aluminium parts that touch the carbon plate (spacer bars, front stops, corner spacers, standoffs) are anodised; the plate's cut edges are sealed with epoxy.
- M4 nuts on the carbon plate sit on washers and are tightened to about 2 N·m so they do not crush the laminate.
- The countersinks leave 0.4 mm of plate under each M3 head. If the heads pull through or the laminate cracks at TRL 4, the fallback is bonded flush inserts (register, T7).
- Making sketches KWC-DWG-101, 102, 104, 105 and 107 go to Rev P2. KWC-DWG-109 is new. The general arrangement KWC-DWG-001 goes to Rev P2.

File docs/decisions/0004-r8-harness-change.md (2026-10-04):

---
doc_id: KWC-DDR-004
title: Kitewright Core R8 common core, bench harness change between frames
project: Kitewright Core
doc_type: Design decision record
version: "0.1"
status: Draft
date: '2026-10-04'
author: Amish Chadha
license: CERN-OHL-S-2.0
revisions:
- version: "0.1"
  date: '2026-10-04'
  author: Amish Chadha
  change: Amish's round-3 decision 7A (option A of register item O2) recorded and carried out
---

# 0004: R8 common core: accept a bench harness change between frames

- **Date:** 2026-10-04
- **Status:** accepted. Decided by Amish Chadha (owner) on 2026-10-04: "For round 3, I agree with all your proposed recommendations"" (round 3, item 7A).

## Context

Since decision 33B (KWC-DDR-003) each frame's power leads are soldered to the core's board pads, so a core moved between Kitewright Lift and Kitewright Range needs its harness changed: lid off, four 8 AWG leads desoldered and the other frame's soldered on. R8 read "parameter changes only". The point was put to Amish as register item O2.

## Options considered

| Option | What changes | Effect | Cost and mass |
| --- | --- | --- | --- |
| A | Accept a bench harness change (about 30 min, lid off) and restate R8 | R8 met as restated; R9 stays met | None |
| B | Four M4 studs on the board's pads and ring lugs on the frame leads | R8 closer to its wording; R9 missed by about 2 g | About 12 g and USD 15 more |
| C | AS150 plugs back on short core pigtails | R8 met as written; R9 not met (about 1.06 kg) | About 70 g more |

## Decision

Option A, as recommended. R8 is restated in KWC-REQ-001 v0.4: "Same core flies Lift and Range with parameter changes and a change of the frame's power harness at the board." No change to the model, drawings, bill of materials or calculations; the build plan's step 11 already describes the soldered harness, and section 5 now says how a core moves between frames.

## Consequences

- R8 is met by design as restated; R9 stays at 0.99 kg (met on paper).
- The TRL 4 check of R8 is one bench swap by the builder, timed.
- The Kitewright interface table of 2026-10-04 (decision 10A) fixes the frames' side of the swap: the same 220 x 130 mm M4 fixing and AS150 harness plugs on both frames.

> **Safety:** Soldering 8 AWG leads takes a 100 W iron; disconnect every pack first, check polarity with a meter at the AS150 plugs before the first pack goes on, and redo safety stop 2 after every harness change.

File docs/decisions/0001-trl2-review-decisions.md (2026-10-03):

---
doc_id: KWC-DDR-001
title: Kitewright Core TRL 2 review decisions
project: Kitewright Core
doc_type: Design decision record
version: "0.1"
status: Draft
date: '2026-10-03'
author: Amish Chadha
license: CERN-OHL-S-2.0
revisions:
- version: "0.1"
  date: '2026-10-03'
  author: Amish Chadha
  change: TRL 2 review decisions D1 to D15, decided under Amish's 2026-10-03 pre-approval
---

# 0001: TRL 2 review decisions

- **Date:** 2026-10-03
- **Status:** accepted. Decided by Amish under his pre-approval of 2026-10-03: "start with the first 14 repos from the list of 29 projects. I pre-approve the batch runs along with any recommendations you come up with. I also accept any cost overruns or variations from the assumed scope cost." and, for this second batch, "Proceed with the remaining 15 scaffolds".

## Context

The scaffold (KWC-PRB-001 v0.1, KWC-PRC-001 v0.1) left five open questions and several choices that the TRL 2 concept and TRL 3 calculations need settled: the flight stack, the controller class, the bus voltage, the payload class, how the mount works, how the core meets a frame, and where optional parts go. The TRL 2 review (`docs/REVIEW.md`, TRL 2 section) listed each with options and a recommendation. Under Amish's pre-approval every recommendation below is decided. Partners and regions are recorded as the first candidate to approach, not as agreed. Choices that touch safety take the conservative option and say what evidence would relax it. Requirements that the design does not meet are not decided here; they are put to Amish in `docs/REVIEW.md`.

## Options considered and decision

*Table 1. Decisions.*

| # | Item | Options considered | Decision | Why |
| --- | --- | --- | --- | --- |
| D1 | Flight stack | PX4; ArduPilot; both equal | PX4 for the whole family; ArduPilot kept as a documented alternative | R10 names PX4; PX4 runs multirotor and standard VTOL from one release |
| D2 | Flight controller class | FMUv6X class (triple IMU, heater, Ethernet); FMUv6C class; non-standard boards | FMUv6X class on the standard baseboard | IMU heater for cold boots, Ethernet for DS-014, 16 outputs for both frames, rated -40 to +85 °C |
| D3 | Power bus | Fixed 12S; fixed 6S; 18 to 60 V window | 18 to 60 V at the pack inputs (6S Li-ion to 16S LiFePO4); two inputs, two outputs, AS150 anti-spark connectors | One board for a light Range and a heavy Lift; ColdCell may use Li-ion, LiFePO4 or sodium-ion |
| D4 | Payload class | One class; light and heavy classes | One class for version 1: 5 kg and 100 W | Covers Lift's sea-level payload and every planned payload; one shoe and one test |
| D5 | Mount mechanism | Plain rail with rear entry and front stops; side-loading rail; quick-release plate on four pins | Plain rail under the plate, shoe enters from the rear to two front stops, DS-014 on a hand-plugged pigtail | Keeps the patent design-around (no bayonet); a pigtail avoids a blind-mating connector that DS-014 parts are not rated for |
| D6 | Payload retention (safety) | One locking pin; two independent pins; pin plus lanyard | Two independent spring locking pins, each with a red band that shows when it is withdrawn | Conservative choice: a released payload is a falling object. Evidence that would relax it to one pin: a vibration test at flight levels and a pull test showing a single pin cannot back out, on the built mount at TRL 4 |
| D7 | Core to frame | Core on top of the deck; core under the deck with the lid through an opening; frame-specific mounts | Core hangs under the frame deck on four M4 bolts on a 220 x 130 mm pattern with 8 mm spacers; the deck has a 200 x 112 mm opening for the lid | Payload loads go straight into the frame's hard points; the rail is free under the frame; one pattern for both frames |
| D8 | Companion computer | Inside the core lid; in its own box on the frame; none | Optional, in its own box on the frame, linked by Ethernet | Keeps 5 W of heat and 60 g out of the core; only some payloads need it |
| D9 | Pack data | DroneCAN; SMBus; analog only | ColdCell reports temperature and charge over DroneCAN | Released PX4 reads DroneCAN batteries without source changes (R10) |
| D10 | Radios | 900 MHz class telemetry and long-range control link; 2.4 GHz only; one combined video link | 900 MHz class telemetry (up to 1 W) and a long-range control link, band and power set per country; for India the 865 to 867 MHz licence-exempt band is the first candidate, to confirm | Range in steep terrain; open MAVLink radios |
| D11 | Altitude parameter sets | One set; three bands; continuous scheduling | Three bands: sea level, 3,000 m and 5,000 m (KWC-CAL-001, Table 6) | Simple to publish and check; matches AltiRig's test points |
| D12 | DS-014 licence | Wait for confirmation; proceed and confirm; own interface | Proceed with the DS-014 connector and pinout and confirm the licence before buying; if it restricts reuse, keep the same connector with Kitewright's own open pinout | Keeps the open standard the family was built around without blocking TRL 3 |
| D13 | Co-design partner | Rescue organisation; research group; both | First candidate to approach: a university glaciology group in Jammu and Kashmir; second: a state disaster response force unit in the same region (not agreed) | Lake survey is the first mission with a clear payload (LakeWatch) |
| D14 | Remote ID and logging | Fit now; fit when required; never | Log every flight on the controller; a remote ID module goes on the CAN bus when a country's rules require it | Certification is out of scope at TRL 3; the slot is kept |
| D15 | Hover-time model | Publish the 47 % figure; publish a model | Publish the model of KWC-CAL-001 section F (47 % with cold packs, 70 % with ColdCell) | R7 needs a model that can be checked against AltiRig and flight logs |

## Consequences

- KWC-PRC-001, KWC-REQ-001 (definitions), KWC-CAL-001 and the model use these decisions.
- D3, D4, D7 and D9 are shared interfaces with Kitewright Lift, Kitewright Range and ColdCell; they are listed under Cross-repo actions in `docs/REVIEW.md`. The sibling repos are not edited from here.
- D6 adds about 55 g and USD 32 against one pin; R9 is affected (see `docs/REVIEW.md`).

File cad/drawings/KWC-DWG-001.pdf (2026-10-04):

CONCEPT, NOT FOR FABRICATION | Kitewright Core · github.com/BoujeeEnjinia1701/kitewright-core

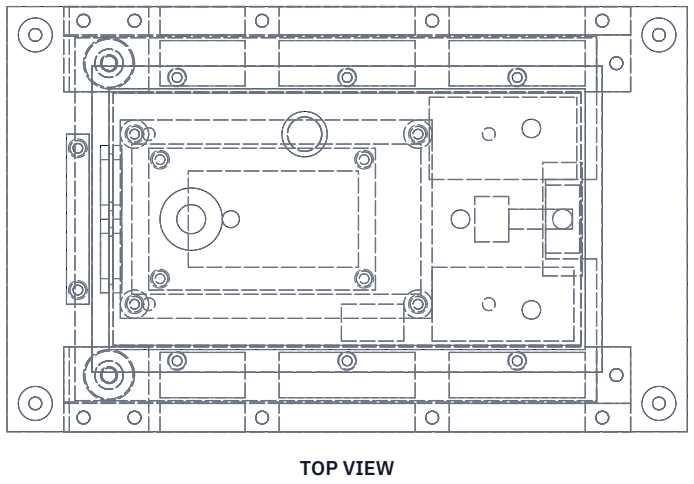
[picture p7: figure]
TOP VIEW

FRONT VIEW
Scale 1:2.5; looking at the front (along +Y)

Scale 1:2.5; looking down (along -Z)

RIGHT VIEW
Scale 1:2.5; looking at the right side (along -X)

240

150 124

ISOMETRIC VIEW
Not to scale; with GNSS mast and antennas; seen from the front right and above, about 30 deg elevation

MAIN DIMENSIONS AND INTERFACES (MM)
Core plate 240 x 150 x 2, carbon; top face is the datum, Z = 0 Frame bolts 4 x M4 on 220 x 130; spacers 12 OD x 8
Frame deck opening 200 x 112 (frame repos)
Lid 168 x 92 x 62, 1.5 walls, 6 x M3 flush studs from below Rails 200 long: spacer 10 x 6, lip 30 x 3
Shoe 184 x 128 x 5; gap to plate 0.3; slides in from the rear Lip overlap 19 each side; payload neck within 88 wide
Two locking pins, 5 mm, at X -84, Y +/-55
DS-014 pigtail through slot 12 x 24 at X 70 to 82
GNSS top 231 above the plate; knob bottom 47 below
Rated payload 5 kg; bus 18 to 60 V; payload 100 W
Frame power leads (Lift or Range) enter via 2 grommets; strain-relief bar Third-angle; X forward along the rail; front view from -Y
REV | DESCRIPTION | DATE | BY
P1 | First issue, constructable design (KWC-DDR-002) | 2026-10-03 | AC
P2 | Decision 33B: carbon plate, pocketed rails, leads to the frames (KWC-DDR-0... | 2026-10-03 | AC
KITEWRIGHT CORE | github.com/BoujeeEnjinia1701/kitewright-core

## Kitewright Core shared avionics and payload core: general arrangement

DRAWING NO.
KWC-DWG-001

REV
P2

SHEET
1 of 1

SIZE

## ANSI B

SCALE
1:2.5

UNITS
mm
PROJECTION | DATE
2026-10-03

DRAWN
Amish Chadha

MATERIAL / NOTES
2 mm carbon plate, 6061 aluminium rail, printed ASA lid, bought avionics per bom/bom.csv. PRELIMINARY, NOT FOR FABRICATION
Licensed CERN-OHL-S-2.0 · Design Molecule Lab · designmolecule.com | Generated from cad/src; do not edit by hand

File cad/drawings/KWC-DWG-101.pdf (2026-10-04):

BUILD PLAN SKETCH, PLAN NOT YET BUILT Kitewright Core · github.com/BoujeeEnjinia1701/kitewright-core

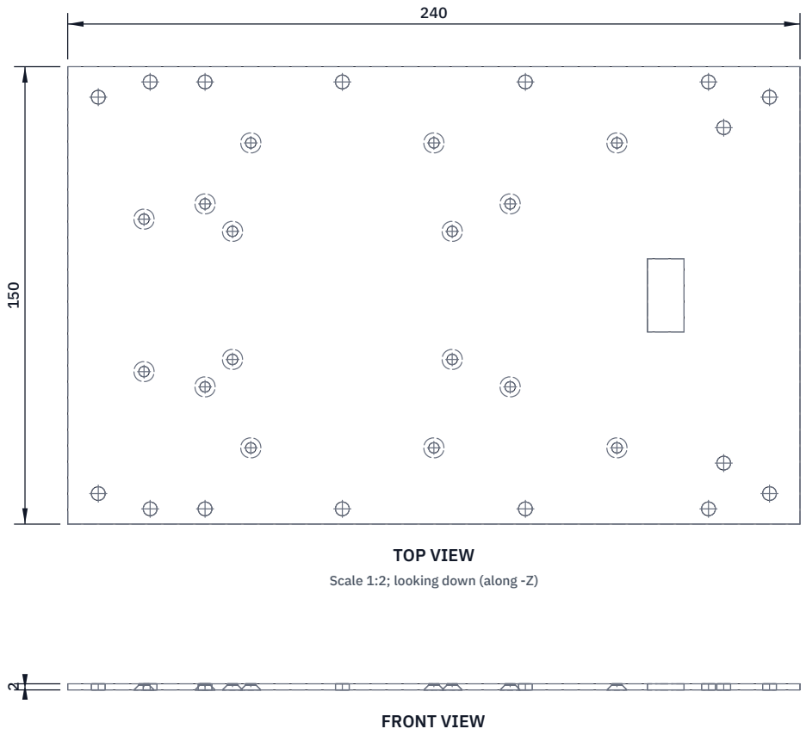
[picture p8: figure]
FRONT VIEW; TOP VIEW; Scale 1:2; looking down (along -Z)

Scale 1:2; looking at the front (along +Y)

RIGHT VIEW
Scale 1:2; looking at the right side (along -X)

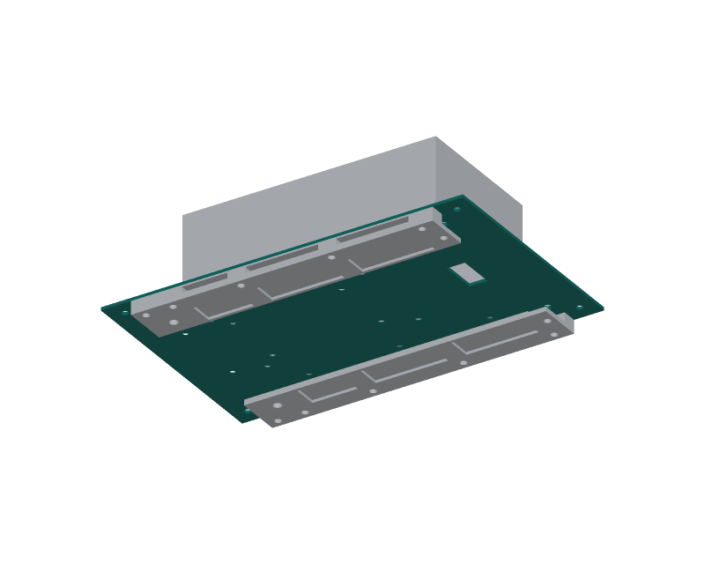
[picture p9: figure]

WHERE IT GOES
This part in colour, its neighbours in grey

HOW TO MAKE IT AND HOW IT FITS
240 x 150 mm, 2 mm carbon sheet, CNC-cut from the DXF. Origin at the centre; X is positive toward the front, Y to the left; top face is the datum.
Frame holes 4.5 mm at 110 mm each side of centre, 65 mm each side (4). Rail holes 4.5 mm on lines 70 mm each side: at -93, -75, -30, 30, 90
mm along X on both lines; stop holes 4.5 mm at 95 mm, 55 mm each side. M3 holes 3.4 mm (16), countersunk 90 deg from the UNDERSIDE to
6.6 mm: lid flange at -60, 0, 60 mm, 50 each side; 25 mm standoffs
at -75 and 25 mm, 30 each side; 8 mm standoffs at -66 and 6 mm,
21 each side; strain-relief bar at -95 mm, 25 each side.
Cable slot 12 x 24 mm from 70 to 82 mm along X, on the centre line. Seal the cut edges with thin epoxy; wear a mask (carbon dust). Check: M3 countersunk heads sit flush underneath (the shoe slides 0.3 mm below); run a straight edge across; nothing proud.
REV | DESCRIPTION | DATE | BY
P1 | Making sketch for the prototype build plan | 2026-10-03 | AC
P2 | Lightened under Amish's decision 33B (KWC-DDR-003) | 2026-10-03 | AC
KITEWRIGHT CORE | github.com/BoujeeEnjinia1701/kitewright-core

## Kitewright Core plate: making sketch

DRAWING NO.
KWC-DWG-101

REV
P2

SHEET
1 of 1

SIZE

## ANSI B

SCALE
1:2

UNITS
mm
PROJECTION | DATE
2026-10-03

DRAWN
Amish Chadha

MATERIAL / NOTES
Carbon fibre sheet 2 mm, 3K twill, CNC-cut
Licensed CERN-OHL-S-2.0 · Design Molecule Lab · designmolecule.com | Generated from cad/src; do not edit by hand

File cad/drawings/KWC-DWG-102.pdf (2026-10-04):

BUILD PLAN SKETCH, PLAN NOT YET BUILT Kitewright Core · github.com/BoujeeEnjinia1701/kitewright-core

FRONT VIEW
Scale 1:1; looking at the front (along +Y)

TOP VIEW
Scale 1:1; looking down (along -Z)

RIGHT VIEW
Scale 1:1; looking at the right side (along -X)

200

10 6

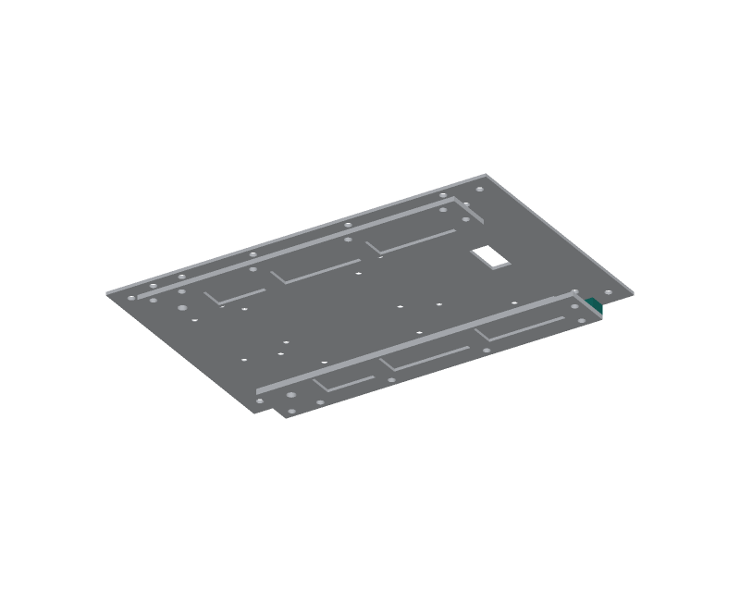
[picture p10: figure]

WHERE IT GOES
This part in colour, its neighbours in grey

HOW TO MAKE IT AND HOW IT FITS
Make two, the same. Saw 10 x 6 mm bar to 200 mm; square the ends. Lay it 6 mm side down. Mark a centre line 5 mm from each edge. Holes 4.5 mm on the centre line at 7, 25, 70, 130 and 190 mm
from the rear end (X = -93, -75, -30, 30 and 90 mm).
Mill three windows 3.6 mm tall through the 10 mm width, centred on the 6 mm height (1.2 mm left top and bottom): X -66 to -36, -24 to 24 and 36 to 84 mm (34 to 64, 76 to 124, 136 to 184 from the rear). Deburr and clear-anodise (it touches the carbon plate).
Check: lay it under the plate and look through all five holes.
REV | DESCRIPTION | DATE | BY
P1 | Making sketch for the prototype build plan | 2026-10-03 | AC
P2 | Lightened under Amish's decision 33B (KWC-DDR-003) | 2026-10-03 | AC
KITEWRIGHT CORE | github.com/BoujeeEnjinia1701/kitewright-core

## Kitewright Core rail spacer bar (make 2): making sketch

DRAWING NO.
KWC-DWG-102

REV
P2

SHEET
1 of 1

SIZE

## ANSI B

SCALE
1:1

UNITS
mm
PROJECTION | DATE
2026-10-03

DRAWN
Amish Chadha

MATERIAL / NOTES
Aluminium flat bar 10 x 6 mm, 6061-T6, clear-anodised
Licensed CERN-OHL-S-2.0 · Design Molecule Lab · designmolecule.com | Generated from cad/src; do not edit by hand

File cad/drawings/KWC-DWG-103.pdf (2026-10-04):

BUILD PLAN SKETCH, PLAN NOT YET BUILT Kitewright Core · github.com/BoujeeEnjinia1701/kitewright-core

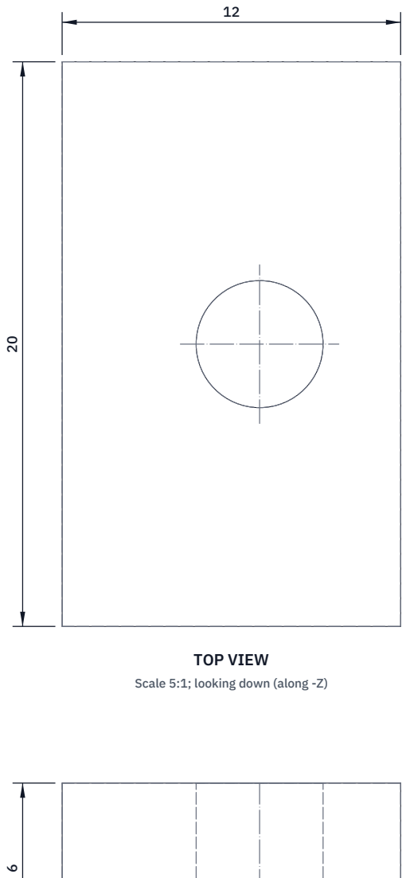
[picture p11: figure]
TOP VIEW; Scale 5:1; looking down (along -Z)

FRONT VIEW
Scale 5:1; looking at the front (along +Y)

RIGHT VIEW
Scale 5:1; looking at the right side (along -X)

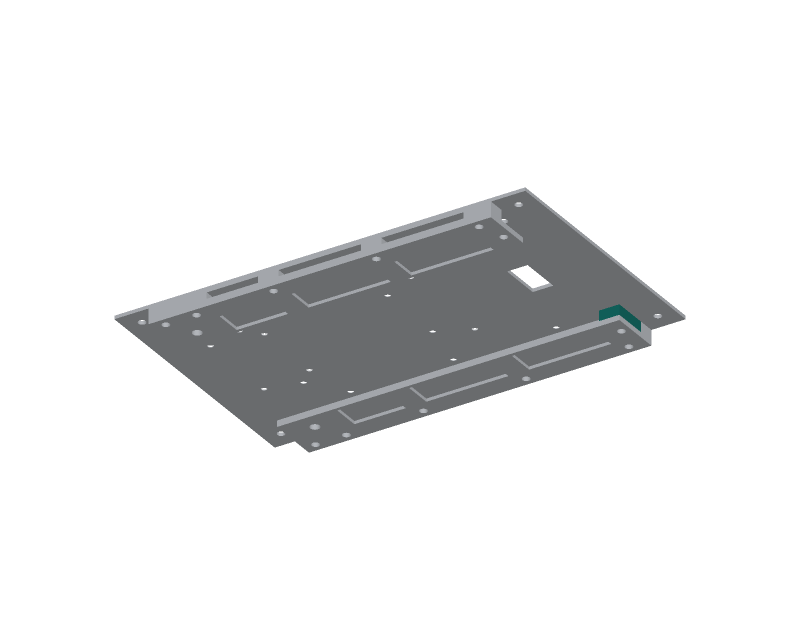
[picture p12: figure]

WHERE IT GOES
This part in colour, its neighbours in grey

HOW TO MAKE IT AND HOW IT FITS
Make two, the same. Saw 20 x 6 mm bar into 12 mm pieces. File the cut ends square: the rear face is where the payload shoe stops, so it must be flat and square to the 6 mm face. Drill one 4.5 mm hole 7 mm from the rear face, 5 mm from the front end and 10 mm from each side.
Fit: between the plate and the lip, against the spacer bar, at the front end of the rail. Its rear face is 12 mm in from the rail's front end.
Check: both stops line up across the plate within 0.2 mm.
REV | DESCRIPTION | DATE | BY
P1 | Making sketch for the prototype build plan | 2026-10-03 | AC
KITEWRIGHT CORE | github.com/BoujeeEnjinia1701/kitewright-core

## Kitewright Core front stop (make 2): making sketch

DRAWING NO.
KWC-DWG-103

REV
P1

SHEET
1 of 1

SIZE

## ANSI B

SCALE
5:1

UNITS
mm
PROJECTION | DATE
2026-10-03

DRAWN
Amish Chadha

MATERIAL / NOTES
Aluminium flat bar 20 x 6 mm, 6061-T6
Licensed CERN-OHL-S-2.0 · Design Molecule Lab · designmolecule.com | Generated from cad/src; do not edit by hand

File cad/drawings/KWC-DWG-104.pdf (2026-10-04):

BUILD PLAN SKETCH, PLAN NOT YET BUILT Kitewright Core · github.com/BoujeeEnjinia1701/kitewright-core

FRONT VIEW
Scale 1:2; looking at the front (along +Y)

TOP VIEW
Scale 1:2; looking down (along -Z)

RIGHT VIEW
Scale 1:2; looking at the right side (along -X)

200

30 3

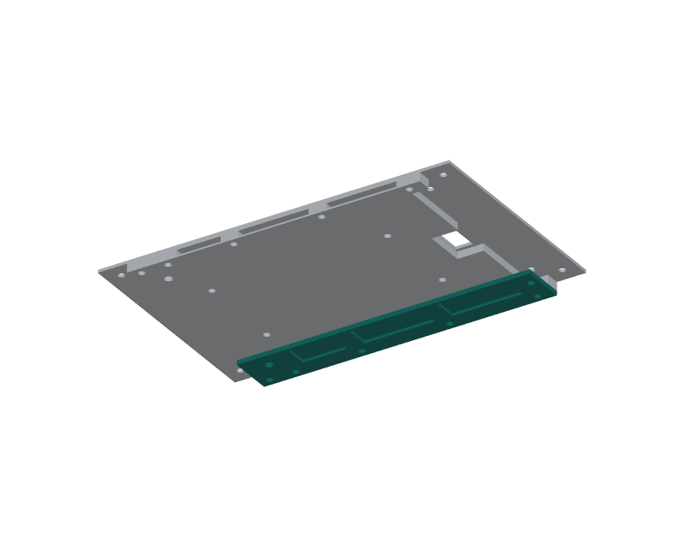
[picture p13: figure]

WHERE IT GOES
This part in colour, its neighbours in grey

HOW TO MAKE IT AND HOW IT FITS
Make a left and a right. Saw 30 x 3 mm bar to 200 mm.
Screw holes 4.5 mm on a line 5 mm from the OUTER edge, at 7, 25, 70, 130 and 190 mm from the rear end; stop hole 4.5 mm at 195 mm, 20 mm from the outer edge.
Pin hole 5.5 mm at 16 mm from the rear end, 20 mm from the outer edge. Countersink the screw holes 90 deg from the UNDERSIDE so the M4 heads sit flush; the left and right lips are mirror images.
Pockets from the UNDERSIDE, 1.8 mm deep, 2 to 18 mm from the inner edge, at 34 to 64, 76 to 124 and 136 to 184 mm from the rear end. Stick 0.7 mm UHMW tape on the top face from the inner edge to 1 mm short of the spacer, rear end to the stop; cut out the pin hole.
Check: a 5 mm shoe offcut slides with a 0.2 to 0.4 mm feeler gap.
REV | DESCRIPTION | DATE | BY
P1 | Making sketch for the prototype build plan | 2026-10-03 | AC
P2 | Lightened under Amish's decision 33B (KWC-DDR-003) | 2026-10-03 | AC
KITEWRIGHT CORE | github.com/BoujeeEnjinia1701/kitewright-core

## Kitewright Core rail lip (make 2, mirror pair): making sketch

DRAWING NO.
KWC-DWG-104

REV
P2

SHEET
1 of 1

SIZE

## ANSI B

SCALE
1:2

UNITS
mm
PROJECTION | DATE
2026-10-03

DRAWN
Amish Chadha

MATERIAL / NOTES
Aluminium flat bar 30 x 3 mm, 6061-T6; UHMW-PE tape 0.7 mm
Licensed CERN-OHL-S-2.0 · Design Molecule Lab · designmolecule.com | Generated from cad/src; do not edit by hand

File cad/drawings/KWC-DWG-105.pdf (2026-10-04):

BUILD PLAN SKETCH, PLAN NOT YET BUILT Kitewright Core · github.com/BoujeeEnjinia1701/kitewright-core

FRONT VIEW
Scale 2:1; looking at the front (along +Y)

TOP VIEW
Scale 2:1; looking down (along -Z)

RIGHT VIEW
Scale 2:1; looking at the right side (along -X)

28

30 12

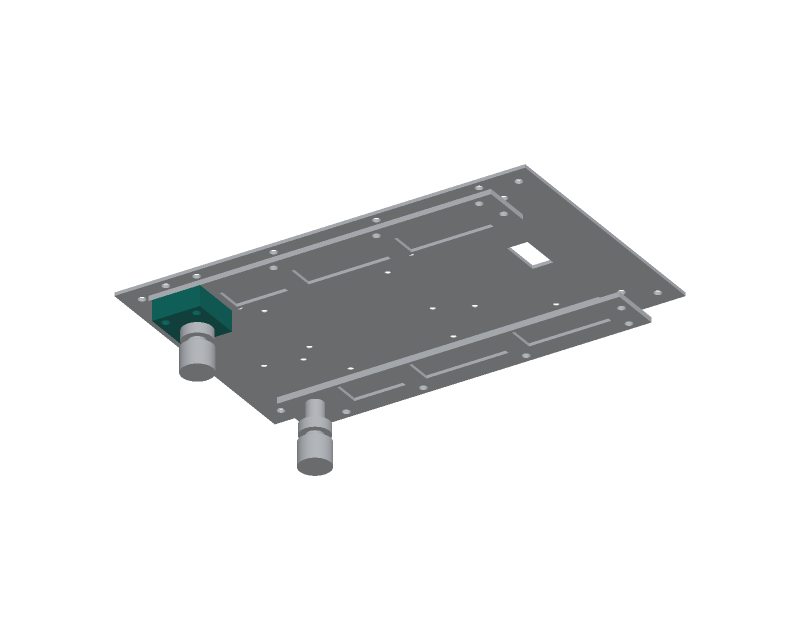
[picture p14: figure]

WHERE IT GOES
This part in colour, its neighbours in grey

HOW TO MAKE IT AND HOW IT FITS
Make two, the same. Saw 30 x 12 mm bar to 28 mm long.
Plunger hole: centre 14 mm from each end, 20 mm from the OUTER face; drill 9.0 mm through, square to the 28 x 30 face, and tap
M10 x 1 (fine thread) all the way.
Two screw holes 4.5 mm, 5 mm from the outer face, at 5 mm and 23 mm from the rear end.
Fit: under the lip at the rear of the rail, outer face flush with
the plate edge; two M4 x 30 cap screws through block, lip, spacer and plate, nylon-insert nuts on top.
Check: the plunger screws in by hand; its pin comes up through the lip hole without touching the sides.
REV | DESCRIPTION | DATE | BY
P1 | Making sketch for the prototype build plan | 2026-10-03 | AC
P2 | Lightened under Amish's decision 33B (KWC-DDR-003) | 2026-10-03 | AC
KITEWRIGHT CORE | github.com/BoujeeEnjinia1701/kitewright-core

## Kitewright Core pin block (make 2): making sketch

DRAWING NO.
KWC-DWG-105

REV
P2

SHEET
1 of 1

SIZE

## ANSI B

SCALE
2:1

UNITS
mm
PROJECTION | DATE
2026-10-03

DRAWN
Amish Chadha

MATERIAL / NOTES
Aluminium bar 30 x 12 mm, 6061-T6
Licensed CERN-OHL-S-2.0 · Design Molecule Lab · designmolecule.com | Generated from cad/src; do not edit by hand

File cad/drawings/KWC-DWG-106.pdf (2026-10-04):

BUILD PLAN SKETCH, PLAN NOT YET BUILT Kitewright Core · github.com/BoujeeEnjinia1701/kitewright-core

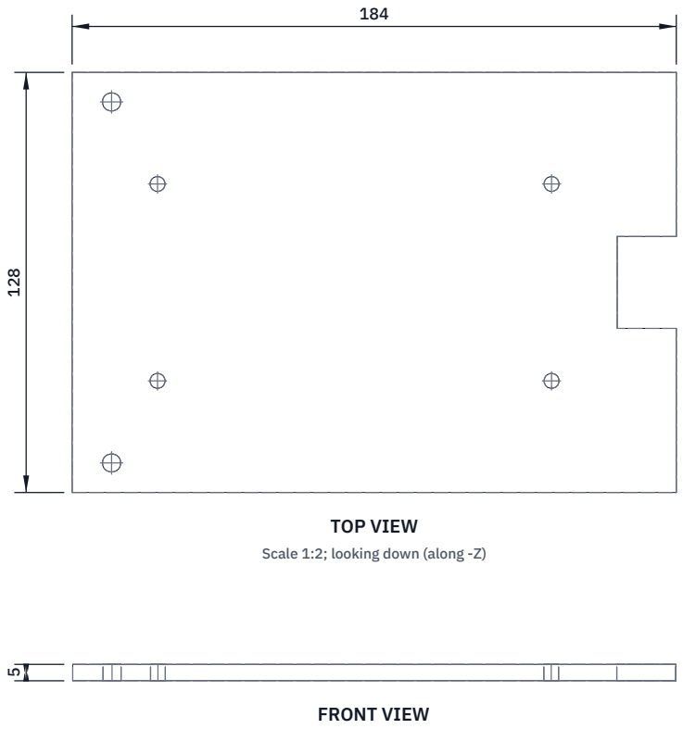
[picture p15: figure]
FRONT VIEW; TOP VIEW; Scale 1:2; looking down (along -Z)

Scale 1:2; looking at the front (along +Y)

RIGHT VIEW
Scale 1:2; looking at the right side (along -X)

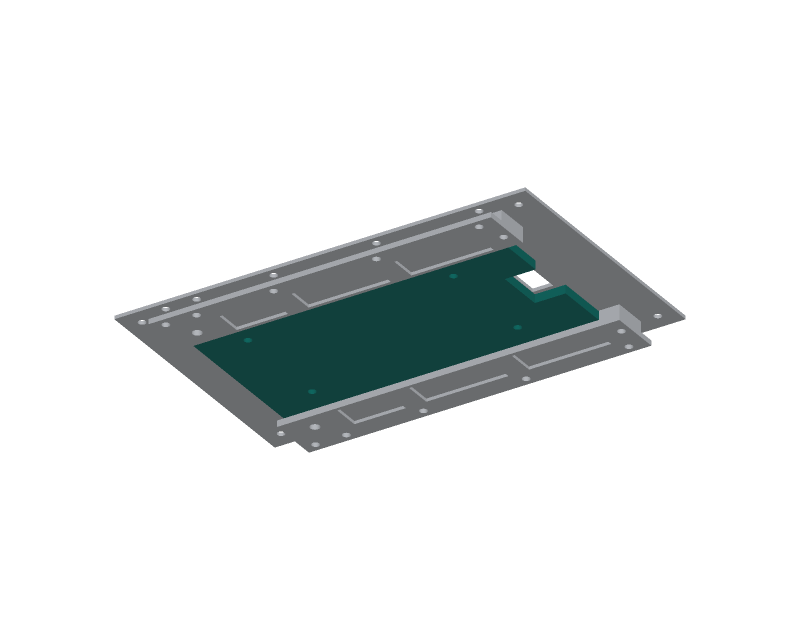
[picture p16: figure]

WHERE IT GOES
This part in colour, its neighbours in grey

HOW TO MAKE IT AND HOW IT FITS
One per payload. Blank 184 x 128 mm from 5 mm plate; ends and long edges square and straight (they run in the rail).
Cable notch in the front edge: 18 mm deep, 28 mm wide, centred. Pin holes 5.5 mm: 12 mm from the rear edge, 9 mm in from each long edge (55 mm each side of the centre line).
Payload holes: four 4.5 mm, countersunk on the TOP face for M4, at 26 and 146 mm from the rear edge, 30 mm each side of centre. Chamfer the rear corners 2 mm so the shoe finds the rail.
Check: slides the full rail length without binding; both pins
drop into their holes at the front stops.
REV | DESCRIPTION | DATE | BY
P1 | Making sketch for the prototype build plan | 2026-10-03 | AC
KITEWRIGHT CORE | github.com/BoujeeEnjinia1701/kitewright-core

## Kitewright Core payload shoe: making sketch

DRAWING NO.
KWC-DWG-106

REV
P1

SHEET
1 of 1

SIZE

## ANSI B

SCALE
1:2

UNITS
mm
PROJECTION | DATE
2026-10-03

DRAWN
Amish Chadha

MATERIAL / NOTES
Aluminium plate 5 mm, 6061-T6
Licensed CERN-OHL-S-2.0 · Design Molecule Lab · designmolecule.com | Generated from cad/src; do not edit by hand

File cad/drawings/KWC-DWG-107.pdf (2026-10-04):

BUILD PLAN SKETCH, PLAN NOT YET BUILT Kitewright Core · github.com/BoujeeEnjinia1701/kitewright-core

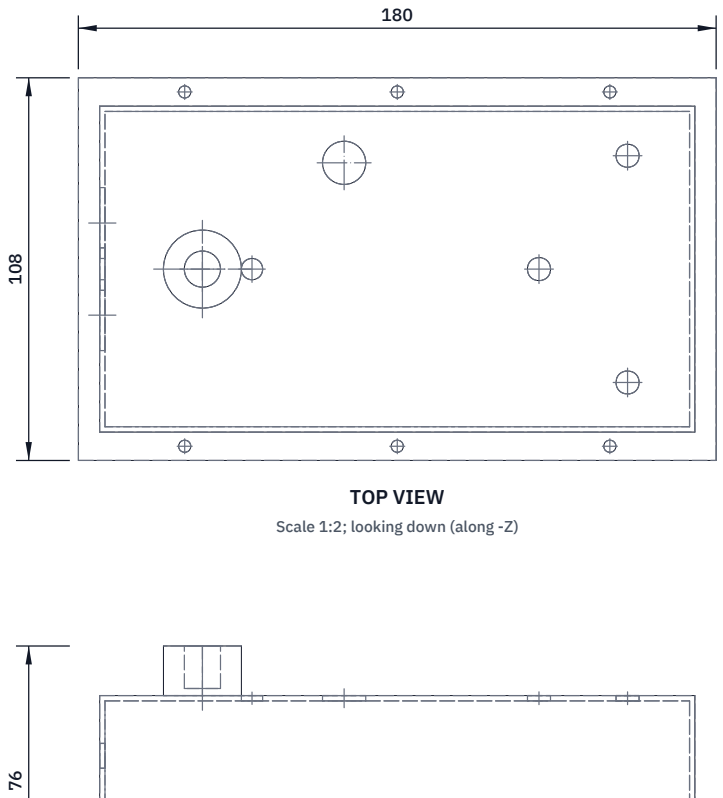
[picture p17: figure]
TOP VIEW; Scale 1:2; looking down (along -Z)

FRONT VIEW
Scale 1:2; looking at the front (along +Y)

RIGHT VIEW
Scale 1:2; looking at the right side (along -X)

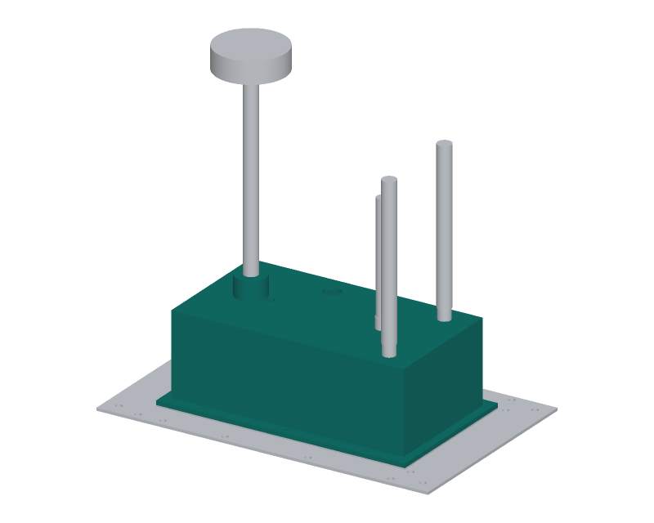
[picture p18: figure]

WHERE IT GOES
This part in colour, its neighbours in grey

HOW TO MAKE IT AND HOW IT FITS
Print open side down on the flange; no supports except the two rear grommet holes and the service opening (bridges).
Outside 168 x 92 x 62 mm, 1.5 mm walls and top; flange 180 x 108 x 3 mm with six 3.4 mm holes, 50 mm each side, at -60, 0, 60 mm. Top: mast boss 22 mm across, 14 mm tall, 10.2 mm socket 12 mm deep, at 55 mm behind centre; heat-set M3 insert in its side
for the thumbscrew; 6 mm GNSS cable hole beside it.
Top: three 6.5 mm SMA holes and a 12.2 mm safety switch hole. Rear wall: two 20 mm grommet holes, 13 mm each side, 17 mm up; 12 x 7 mm service opening for the USB-C lead.
Fit: over the six M3 studs; nylon-insert nuts on the flange.
Check: lid sits flat on the plate on its gasket with no rock.
REV | DESCRIPTION | DATE | BY
P1 | Making sketch for the prototype build plan | 2026-10-03 | AC
P2 | Lightened under Amish's decision 33B (KWC-DDR-003) | 2026-10-03 | AC
KITEWRIGHT CORE | github.com/BoujeeEnjinia1701/kitewright-core

## Kitewright Core lid: making sketch

DRAWING NO.
KWC-DWG-107

REV
P2

SHEET
1 of 1

SIZE

## ANSI B

SCALE
1:2

UNITS
mm
PROJECTION | DATE
2026-10-03

DRAWN
Amish Chadha

MATERIAL / NOTES
3D printed ASA, light grey, 0.2 mm layers, 3 walls, 25 % infill
Licensed CERN-OHL-S-2.0 · Design Molecule Lab · designmolecule.com | Generated from cad/src; do not edit by hand

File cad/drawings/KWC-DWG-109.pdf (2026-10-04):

BUILD PLAN SKETCH, PLAN NOT YET BUILT Kitewright Core · github.com/BoujeeEnjinia1701/kitewright-core

FRONT VIEW
Scale 2:1; looking at the front (along +Y)

TOP VIEW
Scale 2:1; looking down (along -Z)

RIGHT VIEW
Scale 2:1; looking at the right side (along -X)

8

60 2

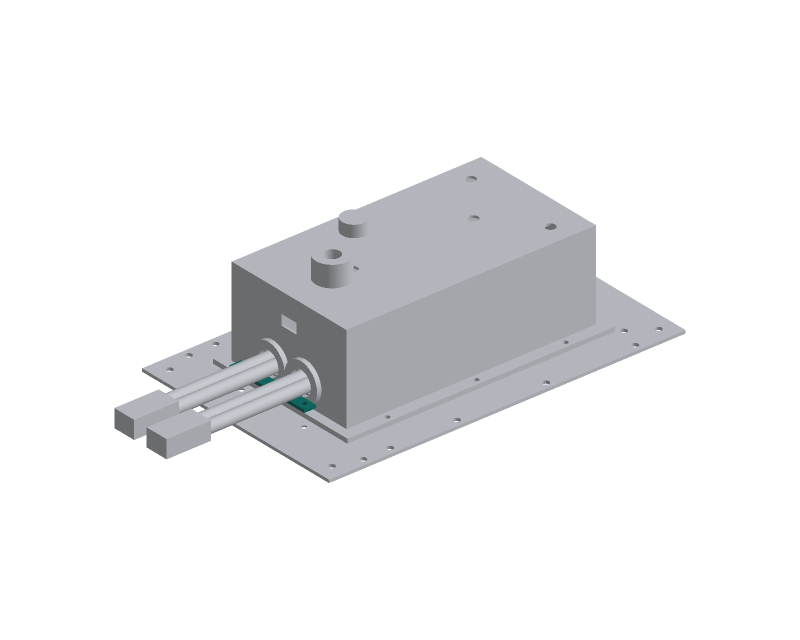
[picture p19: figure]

WHERE IT GOES
This part in colour, its neighbours in grey

HOW TO MAKE IT AND HOW IT FITS
Cut 60 x 8 mm from 2 mm G10, wet or under extraction; wear a mask (glass dust) and file the edges smooth.
Two 3.4 mm holes on the centre line, 25 mm each side of the middle (a 50 mm pattern).
Fit: on two 12 mm M3 female-female standoffs, on countersunk screws set from below the plate at X -95 mm, 25 mm each side, behind the lid; two M3 screws from the top.
The frame's four power leads lie on it and are tied to it with
four UV-stable cable ties (step 11).
Check: it clears the lid flange and the frame deck by 1 mm or more.
REV | DESCRIPTION | DATE | BY
P1 | New part under Amish's decision 33B (KWC-DDR-003) | 2026-10-03 | AC
KITEWRIGHT CORE | github.com/BoujeeEnjinia1701/kitewright-core

## Kitewright Core strain-relief bar: making sketch

DRAWING NO.
KWC-DWG-109

REV
P1

SHEET
1 of 1

SIZE

## ANSI B

SCALE
2:1

UNITS
mm
PROJECTION | DATE
2026-10-03

DRAWN
Amish Chadha

MATERIAL / NOTES
G10 / FR4 glass-epoxy sheet 2 mm (offcut of the damping plate sheet)
Licensed CERN-OHL-S-2.0 · Design Molecule Lab · designmolecule.com | Generated from cad/src; do not edit by hand

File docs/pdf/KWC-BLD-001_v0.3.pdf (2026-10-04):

K I T E W R I G H T C O R E · B U I L D P L A N

# Kitewright Core prototype build plan

Design Molecule Lab · designmolecule.com

D O C U M E N T CO N T RO L

Document ID | KWC-BLD-001 | Version | 0.3
Status | Draft | Date | 2026-10-04
Author | Amish Chadha | License | CERN-OHL-S-2.0
Project TRL | TRL 3 | Proof of concept
Repository | github.com/BoujeeEnjinia1701/kitewright-core
Source | docs/05-build-plan.md @ uncommitted

R EV I S I O N H I STO RY

Version | Date | Author | Change
0.3 | 2026-10-04 | Amish Chadha | Amish's round-3 decision 7A (KWC- DDR-004); step 11 says how a core moves between frames
0.2 | 2026-10-03 | Amish Chadha | Amish's decision 33B carried out (KWC-DDR-003); carbon plate with countersunk fixings, pocketed rail bars, lighter pin blocks, corner spacers and lid; new strain-relief bar (3.9); power leads now come with the frame (step 11)
0.1 | 2026-10-03 | Amish Chadha | First build plan; design made constructable (KWC-DDR-002)

D R A F T · N O T F O R F A B R I C A T I O N

## Kitewright Core prototype build plan

Plan, not yet built. How to build the first proof-of-concept prototype, component by component. Building and testing to it is TRL 4 work. Decisions still to be made are kept in the design decisions register (docs/06-design-decisions.md), not here.

### 1. What you are building


Figure 1. Every component of the core, pulled apart and numbered in build order.
The prototype is one Kitewright Core: a 240 x 150 mm carbon fibre plate with the avionics on top under a printed lid, and the payload rail and two locking pins underneath, plus one payload shoe. Figure 1 shows its 18 components in the order you make or fit them. Nine are made: the core plate (cut by a carbon-cutting service from the drawing), and, in a small workshop, the rail spacer bars, front stops, rail lips, pin blocks, payload shoe, lid, damping plate and strain-relief bar. Everything else is bought and fitted: the flight controller, GNSS receiver, power board and modules, radios, antennas, the DS-014 pigtail, the locking pins (indexing plungers), dampers, standoffs and countersunk screws. The power leads and their AS150 plugs are not part of the core: Kitewright Lift and Kitewright Range each bring their own, and they are soldered in when the core goes into the frame (step 11). The work is sawing, drilling, milling small pockets, tapping and filing aluminium bar, one 3D print, cutting glass-epoxy sheet, and soldering heavy power leads. The parts cost about USD 1,767 for the airborne core from the bill of materials; the ground station kit is bought complete. The core weighs about 0.99 kg.

Safety: The finished core switches lithium pack power of up to 60 V and 200 A. Until section 6 says otherwise, power it only from a current-limited bench supply, never from a pack. Soldering 8 AWG leads needs a 100 W iron or better and gets the wire hot enough to burn: hold it with pliers. Cut aluminium edges and glass-epoxy and carbon dust are hazards: deburr every edge, wear gloves and a dust mask, and cut or file G10 and carbon wet or under extraction. Printing ASA gives off fumes; print in a ventilated space.
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

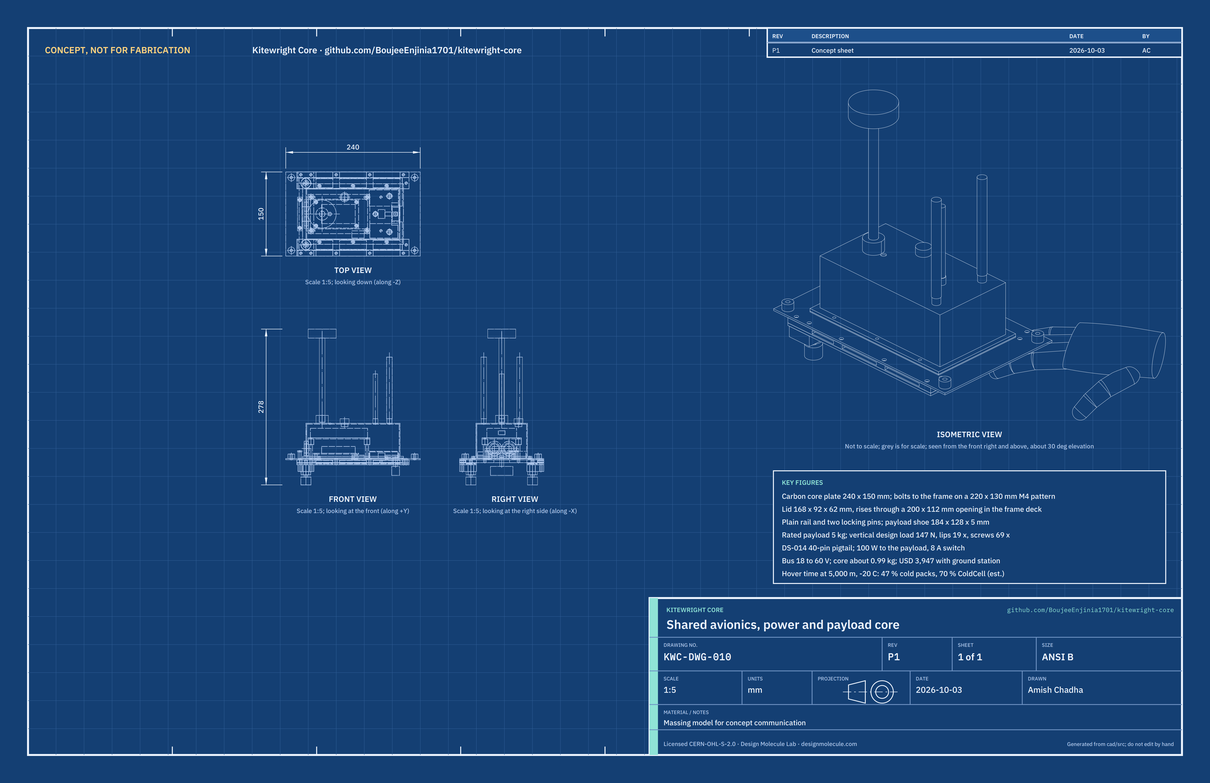
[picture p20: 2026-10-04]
media/concept-blueprint.png

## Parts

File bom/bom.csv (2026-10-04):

item | qty | spec | supplier | unit_cost_usd | make_buy | notes | group
1 Core plate | 1 | Carbon fibre sheet 2 mm (3K twill, epoxy, quasi-isotropic layup), CNC-cut to 240 x 150 mm from the DXF; 4 frame holes 4.5 mm on 220 x 130 mm; rail, stop and block holes 4.5 mm; 16 holes 3.4 mm countersunk 90 degrees from below to 6.6 mm for flush M3 heads; cable slot 12 x 24 mm (KWC-DWG-101) | Carbon sheet CNC-cutting service (drone-frame class) or composite stockist | 58.00 | make | Decision 33B (was 2 mm 5052 aluminium, USD 18). Price basis: drone-frame CNC carbon cutting services quote about USD 40 to 70 for a 2 mm plate this size (estimate). Seal cut edges with thin epoxy; aluminium parts that touch it are anodised | air
2 Corner spacers | 4 | Aluminium round spacer 12 mm OD x 8 mm, 4.5 mm bore (M4 clearance), anodised | Fastener or standoff supplier (for example McMaster-Carr or Accu) | 1.50 | buy | Between the core plate and the frame's lower deck; 12 mm OD (was 16 mm) under decision 33B; anodised so no bare aluminium touches the carbon plate | air
3 Rail spacer bars | 2 | Aluminium 6061-T6 flat bar 10 x 6 mm, 200 mm long; 5 holes 4.5 mm; three windows 3.6 mm tall through the 10 mm width between the screws; clear-anodised (KWC-DWG-102) | Metal stockist; windows milled and parts anodised by a local machine shop | 9.00 | make | Left and right are the same part. Price basis: USD 4 of bar plus about USD 5 a bar for milling and anodising (estimate; decision 33B) | air
4 Rail lips | 2 | Aluminium 6061-T6 flat bar 30 x 3 mm, 200 mm long; 6 holes 4.5 mm countersunk from below; pin hole 5.5 mm; three pockets 16 mm wide and 1.8 mm deep milled from below between the screws (KWC-DWG-104) | Metal stockist; pockets milled by a local machine shop | 10.00 | make | Left and right are mirror images: countersinks and pockets on the underside. Price basis: USD 5 of bar plus about USD 5 a lip for milling (estimate; decision 33B) | air
5 Wear tape | 1 | UHMW-PE tape 0.7 mm (0.025 in) thick, 25 mm wide, acrylic adhesive, 0.5 m | Industrial tape supplier (for example McMaster-Carr) | 12.00 | buy | Laid on the top face of each lip; sets the 0.3 mm running gap above the shoe | air
6 Front stops | 2 | Aluminium 6061-T6 flat bar 20 x 6 mm, 12 mm long; one 4.5 mm hole (KWC-DWG-104) | Metal stockist (offcut of line 3 stock) | 1.00 | make | Sandwiched between the plate and the lip at the front end of each rail; clear-anodise with the spacer bars (carbon plate) | air
7 Pin blocks | 2 | Aluminium 6061-T6 bar 30 x 12 mm, 28 mm long; M10 x 1 tapped hole; two 4.5 mm holes (KWC-DWG-105) | Metal stockist | 4.00 | make | One under each lip at the rear; KWC-DDR-002 two independent locking pins; 12 mm bar (was 15 mm) under decision 33B | air
8 Locking pins (indexing plungers) | 2 | Stainless indexing plunger, M10 x 1 thread, 5 mm hardened pin, at least 9 mm stroke, pull knob with rest (lock-out) position, plus M10 x 1 jam nut | Machine-part supplier (for example a GN 617 class plunger from Ganter or Kipp) | 28.00 | buy | Paint a red band on each pin shank so a withdrawn pin shows red; KWC-DDR-002 | air
9 Payload shoe | 1 | Aluminium 6061-T6 plate 5 mm, 184 x 128 mm; two pin holes 5.5 mm; cable notch 18 x 28 mm; four M4 countersunk holes (KWC-DWG-106) | Metal stockist or laser-cutting service | 22.00 | make | One shoe per payload; the core kit carries one for interface checks; not counted in the core mass | air
10 Lid | 1 | 3D printed ASA, light grey, 168 x 92 x 62 mm with 180 x 108 mm flange, 1.5 mm walls and top, mast boss (KWC-DWG-107); about 90 g of filament | Any ASA filament (1 kg spool about USD 30) | 5.00 | make | Printed open side down; ASA keeps its strength from -20 to +45 degC and resists UV. 1.5 mm walls under decision 33B (was 2 mm). Price basis: 1 kg ASA spool about USD 30, 90 g plus waste | air
11 Lid gasket | 1 | Closed-cell EPDM foam sheet 1 mm, adhesive one side, cut to the flange outline | Industrial tape or gasket supplier | 5.00 | make | Cut from sheet; six 6 mm holes at the flange screws | air
12 Damping plate | 1 | G10 / FR4 glass-epoxy sheet 2 mm, 110 x 70 mm; four 3.4 mm holes and four flight-controller holes (KWC-DWG-108) | Plastics stockist | 8.00 | make | Carries the flight controller on the four dampers | air
13 Vibration dampers | 4 | Silicone grommet dampers for M3, about 10 mm tall, rated -40 degC | Drone parts supplier | 2.00 | buy | Shore hardness to suit the flight controller mass (to confirm when bought) | air
14 Standoffs | 8 | Aluminium M3 female-female standoffs, anodised: four 25 mm and four 8 mm, 5.5 mm hex | Electronics hardware supplier | 0.75 | buy | Screw onto the countersunk M3 screws set from below the carbon plate (line 20) | air
15 Flight controller | 1 | Pixhawk FMUv6X class flight controller with standard baseboard: triple IMU with heater, Ethernet, two CAN buses, 16 PWM outputs, rated -40 to +85 degC, about 102 x 53 x 17 mm (to confirm) | Pixhawk-standard maker (for example Holybro or CUAV) | 390.00 | buy | Runs released PX4 with Kitewright parameter sets | air
16 GNSS receiver and compass | 1 | Multi-band GNSS module with compass, DroneCAN or UART/I2C, about 50 mm diameter, rated -40 degC | Pixhawk-standard maker | 90.00 | buy | On the mast above the lid; may move to a frame position with a longer cable | air
17 GNSS mast | 1 | Carbon fibre tube 10 mm OD x 8 mm ID, 150 mm; M3 thumbscrew and heat-set insert for the lid boss | Composite tube supplier | 8.00 | buy | Removable for transport | air
18 Power distribution board | 1 | Power distribution board 18 to 60 V, 200 A peak, two pack inputs and two frame outputs, Hall current sensor with analog or digital output, 80 x 50 mm (to confirm) | Drone power electronics maker (for example Mauch class) | 120.00 | buy | Measures total current; packs and frame leads solder to its pads | air
19 Power modules | 1 | Set of three: digital power monitor with 5.3 V supply (18 to 60 V in), backup 5.3 V 5 A supply (18 to 60 V in), and payload switch (60 V, 8 A eFuse, enable from the flight controller) | Drone power electronics maker | 150.00 | buy | Two independent supplies for the avionics; the payload switch feeds the DS-014 battery pins | air
20 Countersunk M3 fixings | 16 | Stainless M3 countersunk screws ISO 10642, 8 to 12 mm, set from below the plate with thread-locker; six M3 nylon-insert nuts and washers for the lid flange studs | Fastener supplier | 0.30 | buy | Replace the clinch nuts, which cannot be pressed into carbon (decision 33B). Heads sit flush in the 90 degree countersinks because the shoe slides 0.3 mm below. Price basis: about USD 0.30 a screw with its share of nuts and washers | air
21 Strain-relief bar | 1 | G10 / FR4 bar 60 x 8 x 2 mm with two 3.4 mm holes on 50 mm; two aluminium M3 female-female standoffs 12 mm; two M3 screws; four UV-stable cable ties | Plastics stockist (G10 offcut of line 12) and electronics hardware supplier | 8.00 | make | Behind the lid; the frame's four power leads are tied to it. Decision 33B: the power leads and AS150 plugs (was this line, USD 60) move to each frame's harness (Kitewright Lift and Range). Price basis: standoffs and screws about USD 3, ties USD 1, G10 offcut and cutting about USD 4 | air
22 Telemetry radio pair | 1 | 900 MHz class telemetry radio pair (air and ground), up to 1 W, MAVLink, rated -40 to +85 degC, air module about 52 x 29 x 13 mm (to confirm); band and power to suit the country | Telemetry radio maker (for example RFDesign class) | 400.00 | buy | Ground half goes in the ground station kit | air
23 Control link receiver | 1 | Long-range control link receiver (ExpressLRS 900 MHz or 2.4 GHz class) with telemetry | Drone parts supplier | 30.00 | buy | Pairs with the handset (line 31) | air
24 Antennas and SMA bulkheads | 1 | Two 900 MHz dipole antennas, one control link antenna, three SMA bulkhead pigtails 100 mm | Antenna supplier | 45.00 | buy | Through the three 6.5 mm holes in the lid top | air
25 DS-014 connector pair and pigtail | 1 | 40-pin connector pair as named in Pixhawk DS-014 with latch; 0.3 m pigtail with power and data pairs; cable clamp (part numbers to confirm from the standard) | Connector distributor | 60.00 | buy | Plug hangs in front of the payload through the slot and the shoe notch | air
26 Safety switch and buzzer | 1 | Pixhawk-standard safety switch with LED and buzzer | Pixhawk-standard maker | 15.00 | buy | Switch in the lid top | air
27 Grommets | 2 | Rubber grommets for a 20 mm hole in a 1.5 to 2 mm wall, 16 mm bore | Electrical hardware supplier | 1.00 | buy | Rear wall of the lid; the frame's power leads pass through them, two per grommet | air
28 Signal harness | 1 | Pixhawk-standard JST-GH cables and PTFE-insulated hook-up wire (stays flexible at -20 degC) | Drone parts supplier | 35.00 | buy | Cold-rated harness | air
29 Fasteners | 1 | Stainless kit: M4 countersunk x 16 (12), M4 cap x 35 (4), M4 nyloc nuts (16), M3 cap screws, M3 nylon screws for the flight controller, washers | Fastener supplier | 25.00 | buy | Thread-locker on every metal-to-metal screw | air
30 Companion computer (optional) | 1 | Single-board computer with Ethernet, wide-temperature rated, in its own small enclosure on the frame | Single-board computer distributor | 150.00 | buy | Optional; outside the core lid (KWC-DDR-001 D8) | air
31 Control handset | 1 | Control link handset with telemetry display, rated to -10 degC or kept warm in a jacket | Drone parts supplier | 250.00 | buy | Ground station kit | ground
32 Ground station tablet | 1 | Rugged sunlight-readable tablet rated -20 to +60 degC operating, USB and Wi-Fi, open ground control software (QGroundControl) | Rugged tablet supplier | 900.00 | buy | Ground station kit | ground
33 Ground antenna and tripod | 1 | 900 MHz directional antenna 8 dBi class, tripod, 3 m low-loss cable | Antenna supplier | 120.00 | buy | Ground station kit | ground
34 Field charger | 1 | Dual-channel DC charger 12 to 30 V input, at least 500 W per channel, balance charging for the packs in use | Drone charger maker | 350.00 | buy | Charges only packs that ColdCell has warmed above its charge limit | ground
35 Spares kit | 1 | Second flight controller, GNSS module, control link receiver, two plungers, dampers and fasteners | As above | 560.00 | buy | Field spares | spares

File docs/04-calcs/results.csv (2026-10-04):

requirement | result | target | status
R1 | DS-014 40-pin connector on a 0.3 m pigtail; signals from the flight controller and bus; licence and pinout to confirm | DS-014 signals and power present | Met on paper (licence and pinout to confirm)
R2 | About 52 s with gloves, no tools; pin state shown by a red band | 60 s, no tools, pin visible | Met on paper (estimate)
R3 | Vertical 147 N: lips 19x at the pockets, screws 69x, carbon side beam 8.3x; fore-aft 221 N on one pin 36x, carbon bearing 14x | 3 x and 1.5 x at 2 g, rated 5 kg | Met on paper
R4 | 100 W needs at most 5.6 A (6S at 18 V); switch limit 8 A; DS-014 pin rating to confirm | 100 W continuous at bus voltage | Met on paper (pin rating to confirm)
R5 | Hottest part about 75 degC at 45 degC ambient; cold boot at -20 degC within the -40 degC rating | -20 to +45 degC | Met on paper
R6 | Sensors in range at 54 kPa; failsafe set per altitude band (Table 6); control margin is a frame property | Stable control and failsafes at 5,000 m density | Met on paper (core); flight check needs a frame
R7 | Model published: 47% (cold packs) and 70% (ColdCell) of sea-level hover time at 5,000 m and -20 degC | Within 15 % of measured | Model ready; accuracy shown only at TRL 4
R8 | One core, one interface (Table 7); Lift needs 11 of 16 outputs and Range 10 of 16; parameter sets only; since decision 33B, moving the core between frames also means changing the frame's soldered power harness at the board's pads (open decision O1) | Same core in Lift and Range | Met by design for firmware and fixing; harness change open (O1)
R9 | 0.99 kg estimated (carbon plate, pocketed rails, power leads in the frames' harness; decision 33B) | 1.0 kg or less, excluding batteries | Met on paper (10 g margin; bought-part masses to confirm)
R10 | Released PX4 (v1.15 or later), parameters and stock modules only; ColdCell reports over DroneCAN | Released PX4, no source change | Met by design
R11 | USD 3,946.80 including ground station and spares | Value-engineering target USD 5,000 | Under the target by USD 1,053.20

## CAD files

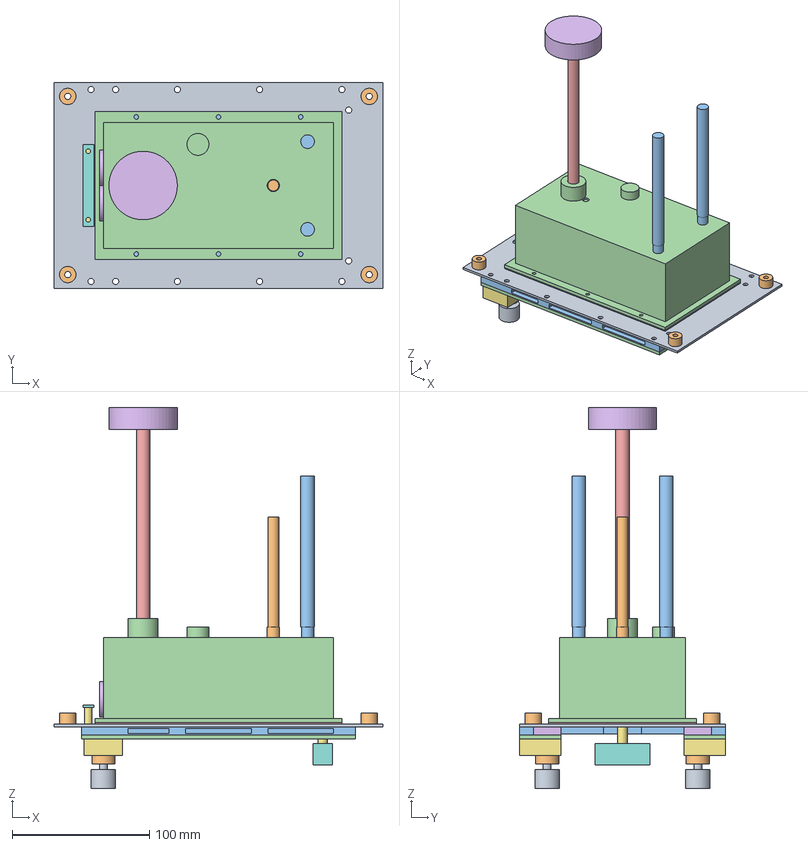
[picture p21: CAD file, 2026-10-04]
cad/step/kitewright-core-assembly.step
240.0 x 150.0 x 278.0 mm

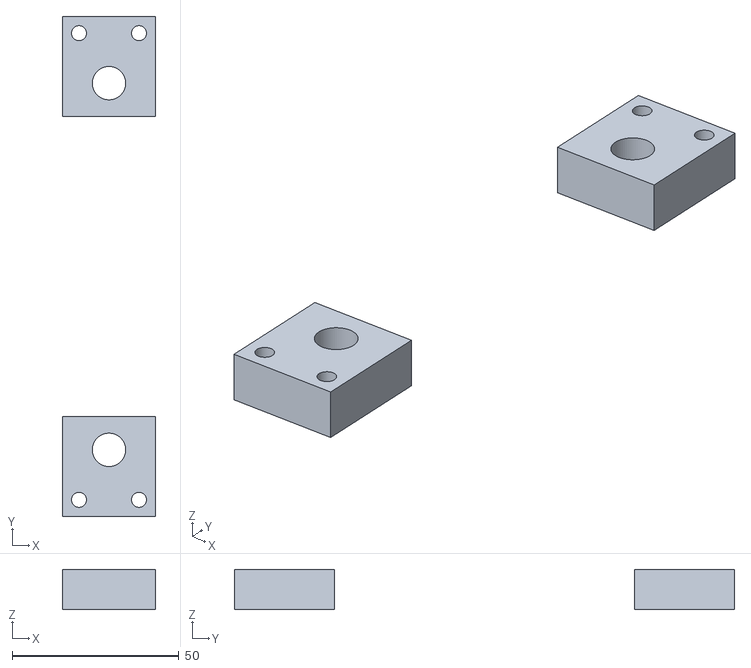
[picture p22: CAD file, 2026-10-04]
cad/stl/kitewright-core-pin-block.stl
28.0 x 150.0 x 12.0

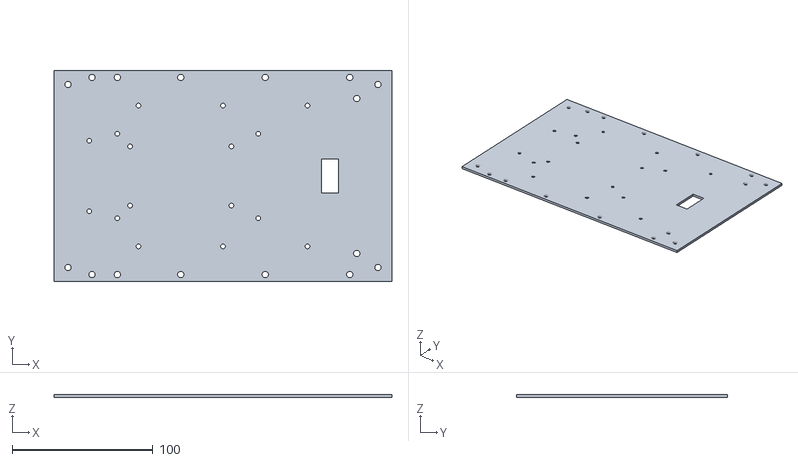
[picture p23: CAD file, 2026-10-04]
cad/stl/kitewright-core-plate.stl
240.0 x 150.0 x 2.00

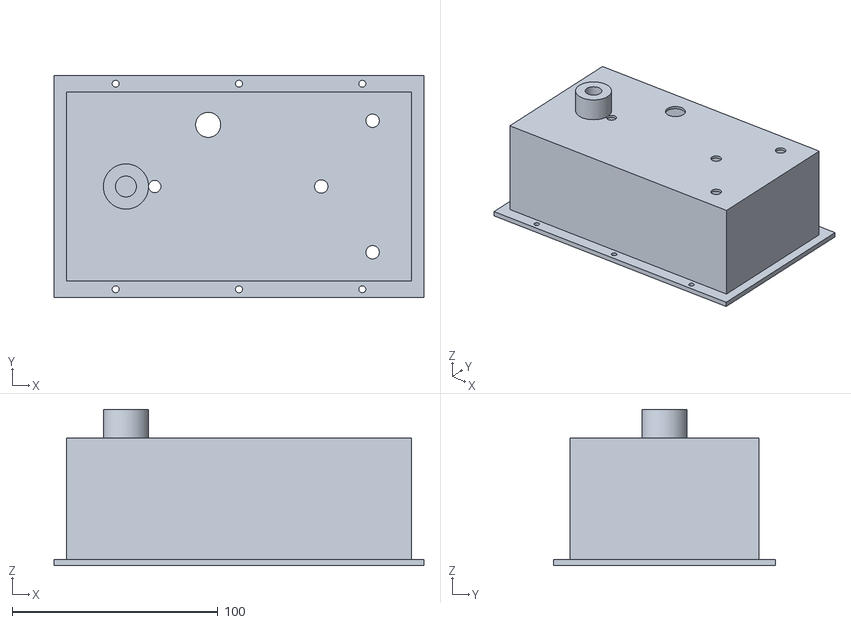
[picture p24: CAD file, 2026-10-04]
cad/stl/kitewright-core-lid.stl
180.0 x 108.0 x 76.0

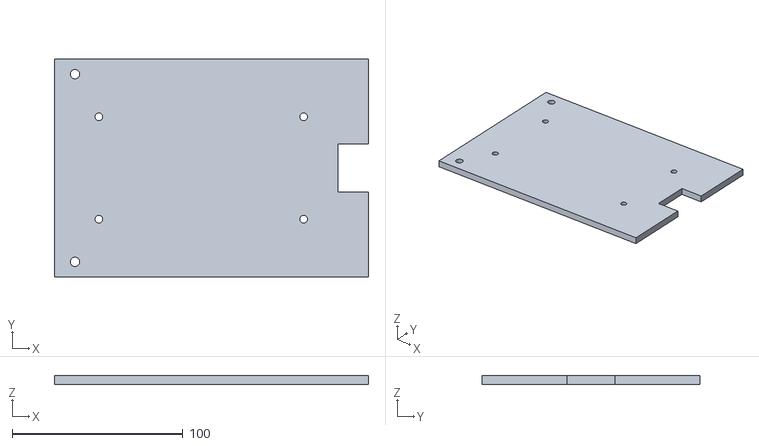
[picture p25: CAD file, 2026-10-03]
cad/stl/kitewright-core-shoe.stl
184.0 x 128.0 x 5.00

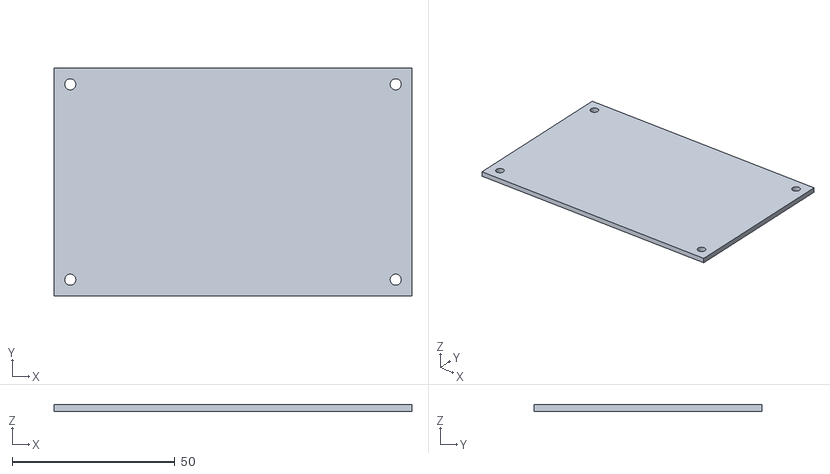
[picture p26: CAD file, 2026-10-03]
cad/stl/kitewright-core-fc-plate.stl
110.0 x 70.0 x 2.00

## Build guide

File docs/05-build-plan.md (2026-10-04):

---
doc_id: KWC-BLD-001
title: Kitewright Core prototype build plan
project: Kitewright Core
doc_type: Build plan
version: "0.3"
status: Draft
date: '2026-10-04'
author: Amish Chadha
license: CERN-OHL-S-2.0
revisions:
  - version: "0.1"
    date: '2026-10-03'
    author: Amish Chadha
    change: First build plan; design made constructable (KWC-DDR-002)
  - version: "0.2"
    date: '2026-10-03'
    author: Amish Chadha
    change: Amish's decision 33B carried out (KWC-DDR-003); carbon plate with countersunk fixings, pocketed rail bars, lighter pin blocks, corner spacers and lid; new strain-relief bar (3.9); power leads now come with the frame (step 11)
  - version: "0.3"
    date: '2026-10-04'
    author: Amish Chadha
    change: Amish's round-3 decision 7A (KWC-DDR-004); step 11 says how a core moves between frames
---

# Kitewright Core prototype build plan

**Plan, not yet built.** How to build the first proof-of-concept prototype, component by component. Building and testing to it is TRL 4 work. Decisions still to be made are kept in the design decisions register ([docs/06-design-decisions.md](06-design-decisions.md)), not here.

## 1. What you are building

Figure 1. Every component, pulled apart and numbered in build order

*Figure 1. Every component of the core, pulled apart and numbered in build order.*

The prototype is one Kitewright Core: a 240 x 150 mm carbon fibre plate with the avionics on top under a printed lid, and the payload rail and two locking pins underneath, plus one payload shoe. Figure 1 shows its 18 components in the order you make or fit them. Nine are made: the core plate (cut by a carbon-cutting service from the drawing), and, in a small workshop, the rail spacer bars, front stops, rail lips, pin blocks, payload shoe, lid, damping plate and strain-relief bar. Everything else is bought and fitted: the flight controller, GNSS receiver, power board and modules, radios, antennas, the DS-014 pigtail, the locking pins (indexing plungers), dampers, standoffs and countersunk screws. The power leads and their AS150 plugs are not part of the core: Kitewright Lift and Kitewright Range each bring their own, and they are soldered in when the core goes into the frame (step 11). The work is sawing, drilling, milling small pockets, tapping and filing aluminium bar, one 3D print, cutting glass-epoxy sheet, and soldering heavy power leads. The parts cost about USD 1,767 for the airborne core from the bill of materials; the ground station kit is bought complete. The core weighs about 0.99 kg.

> **Safety:** The finished core switches lithium pack power of up to 60 V and 200 A. Until section 6 says otherwise, power it only from a current-limited bench supply, never from a pack. Soldering 8 AWG leads needs a 100 W iron or better and gets the wire hot enough to burn: hold it with pliers. Cut aluminium edges and glass-epoxy and carbon dust are hazards: deburr every edge, wear gloves and a dust mask, and cut or file G10 and carbon wet or under extraction. Printing ASA gives off fumes; print in a ventilated space.

## 2. What changed to make it buildable

The scaffold described the core in words; to build it, each part needed a shape, a material and a fixing. Each change below keeps what the core does and is recorded in decision record KWC-DDR-002.

*Table 1. Changes from the concept.*

| Component | The concept had | The buildable design has | Why |
| --- | --- | --- | --- |
| Payload rail | "A plain rail" | Spacer bar and taped lip on each side, bolted under the plate; 0.3 mm gap above the shoe (Figure 12) | Made from stock bar; the gap comes from stock thicknesses |
| Locking pin | "A locking pin" | Two spring plungers in blocks under the lips (Figure 14) | Either pin alone holds the payload |
| End of travel | None | Two front stops between plate and lip (Figure 15) | Lines the pins up with their holes |
| Payload connector | A connector on the mount | A pigtail through a slot in the plate and a notch in the shoe (Figure 21) | A sliding shoe cannot mate a 40-pin plug reliably |
| Fixings under the plate | Not shown | M3 countersunk screws set from below, heads flush (Figure 23) | The shoe slides just under the plate; clinch nuts cannot go into carbon |
| Core plate and rails (decision 33B) | Aluminium plate, solid bars | Carbon fibre plate; windows in the spacer bars and pockets under the lips; thinner pin blocks, corner spacers and lid walls | R9: the core must weigh 1.0 kg or less |
| Power leads (decision 33B) | Four leads with AS150 plugs in the core | The frame's own harness comes in through the grommets and is tied to a strain-relief bar | R9; the lead lengths differ for each frame anyway |
| Core to frame | "Bolts into any frame" | Hangs under the deck on four bolts and spacers (Figure 28) | Payload load goes straight into the frame |
| Flight controller | Not shown | On four dampers and a glass-epoxy plate above the power board (Figure 18) | Vibration isolation |
| Lid | "Cold-rated enclosure" | Printed lid with flange, gasket and six screws | Clears the stop nuts and the deck opening |

## 3. Making the components

Sizes are in millimetres. Positions are given from the centre of the core plate: "along" means toward the front (the end with the cable slot), "across" means to the left or right of the centre line.

### 3.1 Core plate

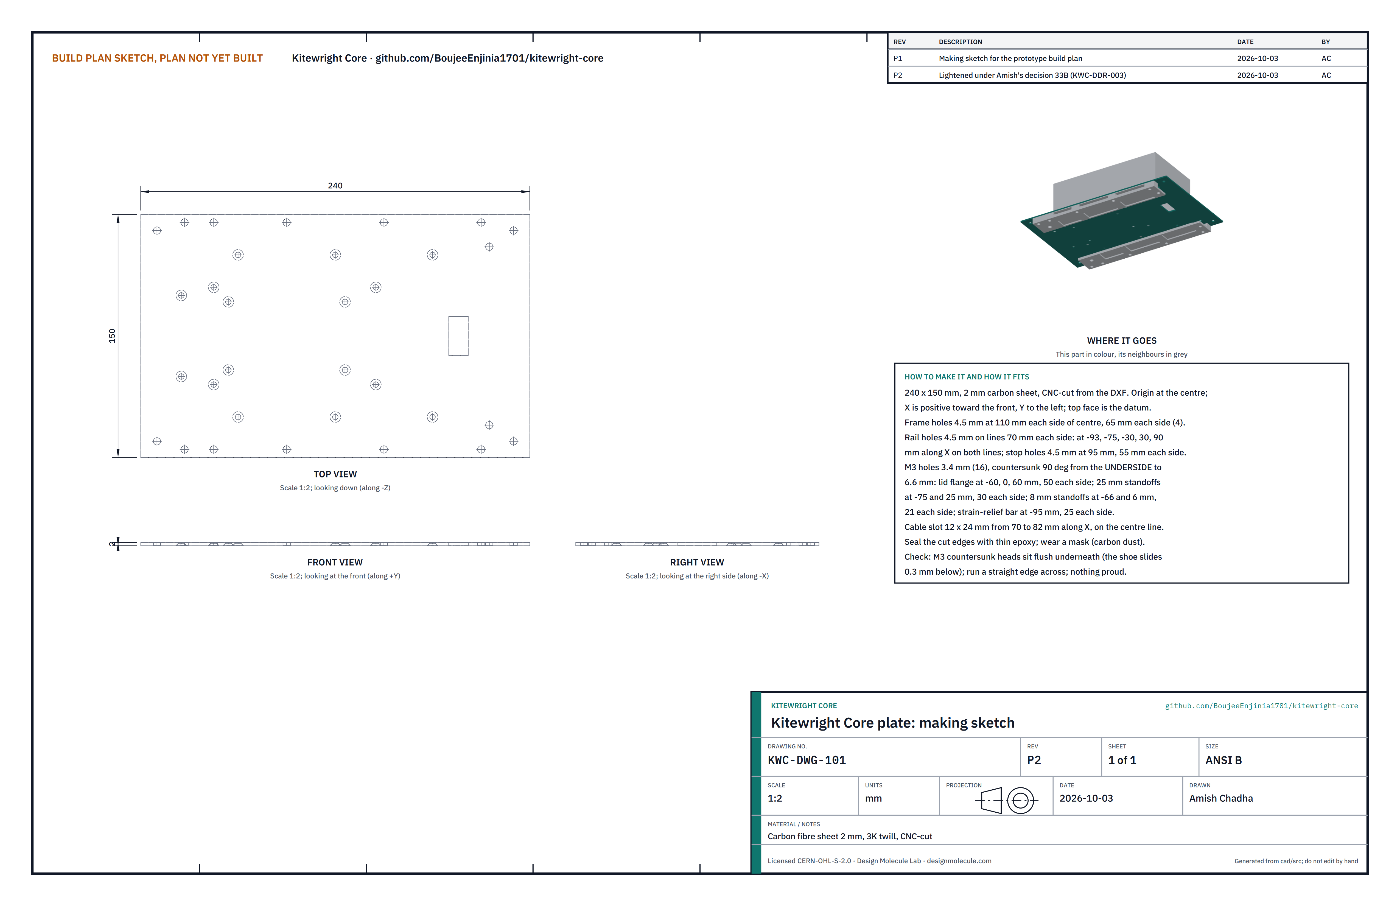
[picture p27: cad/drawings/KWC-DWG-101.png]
Figure 2. Core plate making sketch


*Figure 2. Making sketch KWC-DWG-101, Rev P2.*

**What it is and what it is made from.** The flat plate everything fixes to: 240 x 150 mm of 2 mm carbon fibre sheet (3K twill, quasi-isotropic). Carbon is used because it is light (decision 33B).

**How to make it.** Order it from a carbon-cutting service (the kind that cuts drone frames), sending the outline and holes below as a drawing file. If you cut it yourself, use carbide tools, cut wet or under extraction and wear a mask.

1. Outline 240 x 150 mm, centre lines marked each way.
2. Four frame holes 4.5 mm, 110 mm along each way from the centre and 65 mm across each way.
3. Rail holes 4.5 mm on two lines 70 mm each side of the centre line, at 93 mm and 75 mm behind the centre, 30 mm behind, 30 mm ahead and 90 mm ahead. Two stop holes 4.5 mm at 95 mm ahead, 55 mm each side.
4. Sixteen M3 holes 3.4 mm, each countersunk 90° from the **underside** to 6.6 mm across so an M3 countersunk head sits flush: six for the lid flange (60 mm behind, on the centre, 60 mm ahead; 50 mm each side), four for the tall standoffs (75 mm behind and 25 mm ahead; 30 mm each side), four for the short standoffs (66 mm behind and 6 mm ahead; 21 mm each side) and two for the strain-relief bar (95 mm behind; 25 mm each side).
5. Cable slot 12 mm long and 24 mm wide, from 70 to 82 mm ahead of the centre.
6. Seal every cut edge and hole with a thin coat of epoxy so the fibres do not fray or take up water.

**How it fits the parts next to it.** The rails bolt to its underside (Figure 12). The standoffs and the lid's six studs sit on M3 countersunk screws pushed up through it from below with thread-locker (Figures 18 and 23). It hangs from the frame on its four corner holes (Figure 28). Every aluminium part that touches it is anodised, so the two materials cannot corrode each other in wet snow.

**Check before moving on.** Fit an M3 countersunk screw in each countersink and lay a straight edge across the underside in several directions: nothing stands proud, because the shoe slides 0.3 mm below.

### 3.2 Rail spacer bars (make 2)

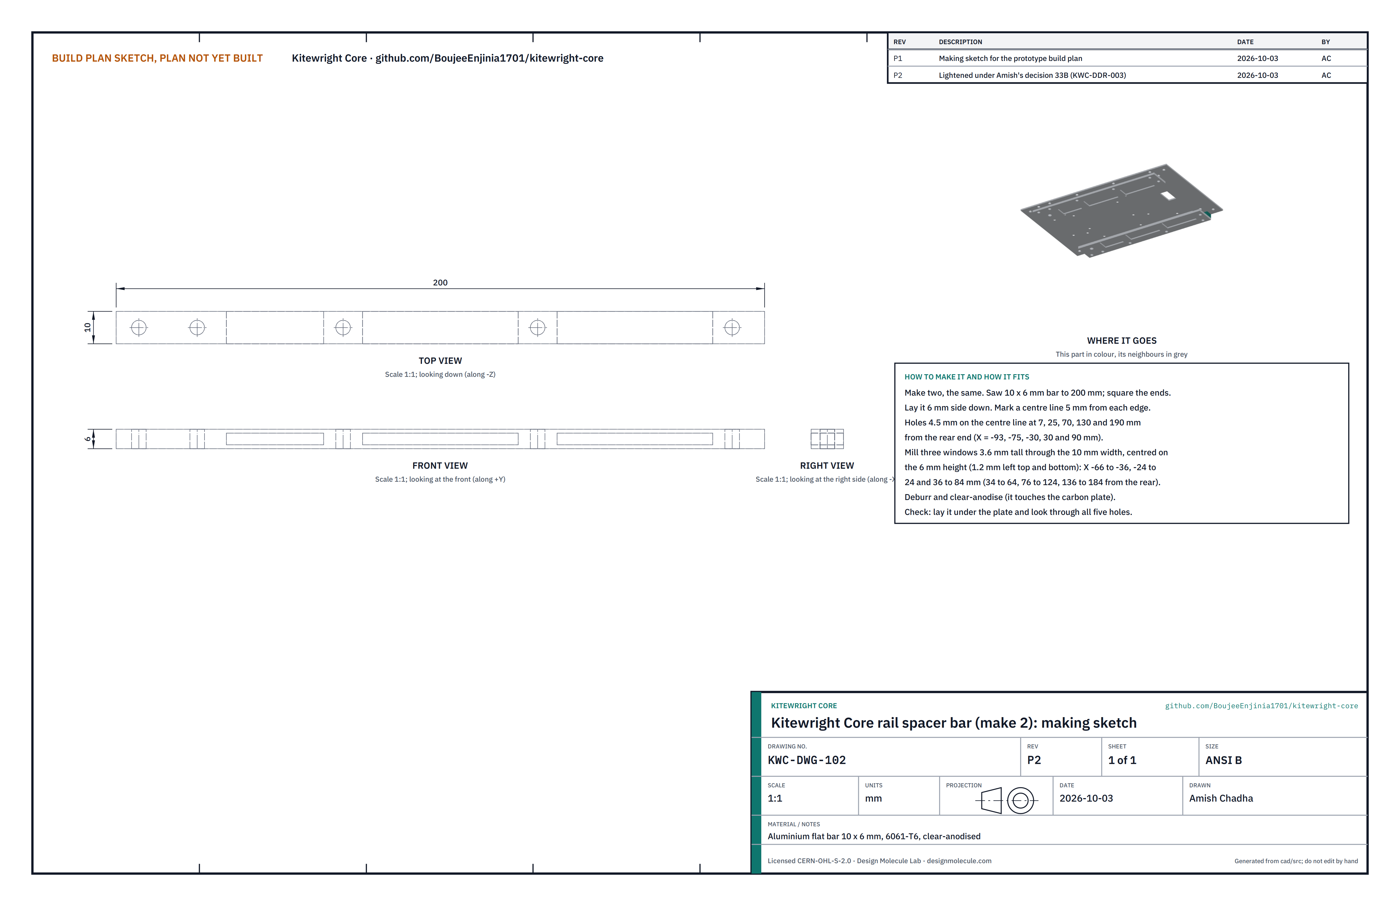
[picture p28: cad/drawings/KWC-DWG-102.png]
Figure 3. Rail spacer bar making sketch


*Figure 3. Making sketch KWC-DWG-102, Rev P2.*

**What it is and what it is made from.** The bar that sets the gap between plate and lip: 10 x 6 mm 6061-T6 flat bar, 200 mm long, with three lightening windows.

**How to make it.**

1. Saw two pieces 200 mm long and square the ends.
2. Mark a centre line along the 10 mm face and drill five 4.5 mm holes on it at 7, 25, 70, 130 and 190 mm from the rear end.
3. Mill three windows right through the 10 mm width, 3.6 mm tall and centred on the 6 mm height, so 1.2 mm of metal is left above and below: 34 to 64 mm, 76 to 124 mm and 136 to 184 mm from the rear end. A small machine shop can do this; it keeps clear of every hole.
4. Deburr, then have both bars clear-anodised (they touch the carbon plate).

**How it fits the parts next to it.** Its 10 mm face lies against the underside of the plate with its outer edge on the plate's long edge; the lip lies under it (Figure 12). The screws pass through all three.

**Check before moving on.** Hold it under the plate and look through all five holes.

### 3.3 Front stops (make 2)

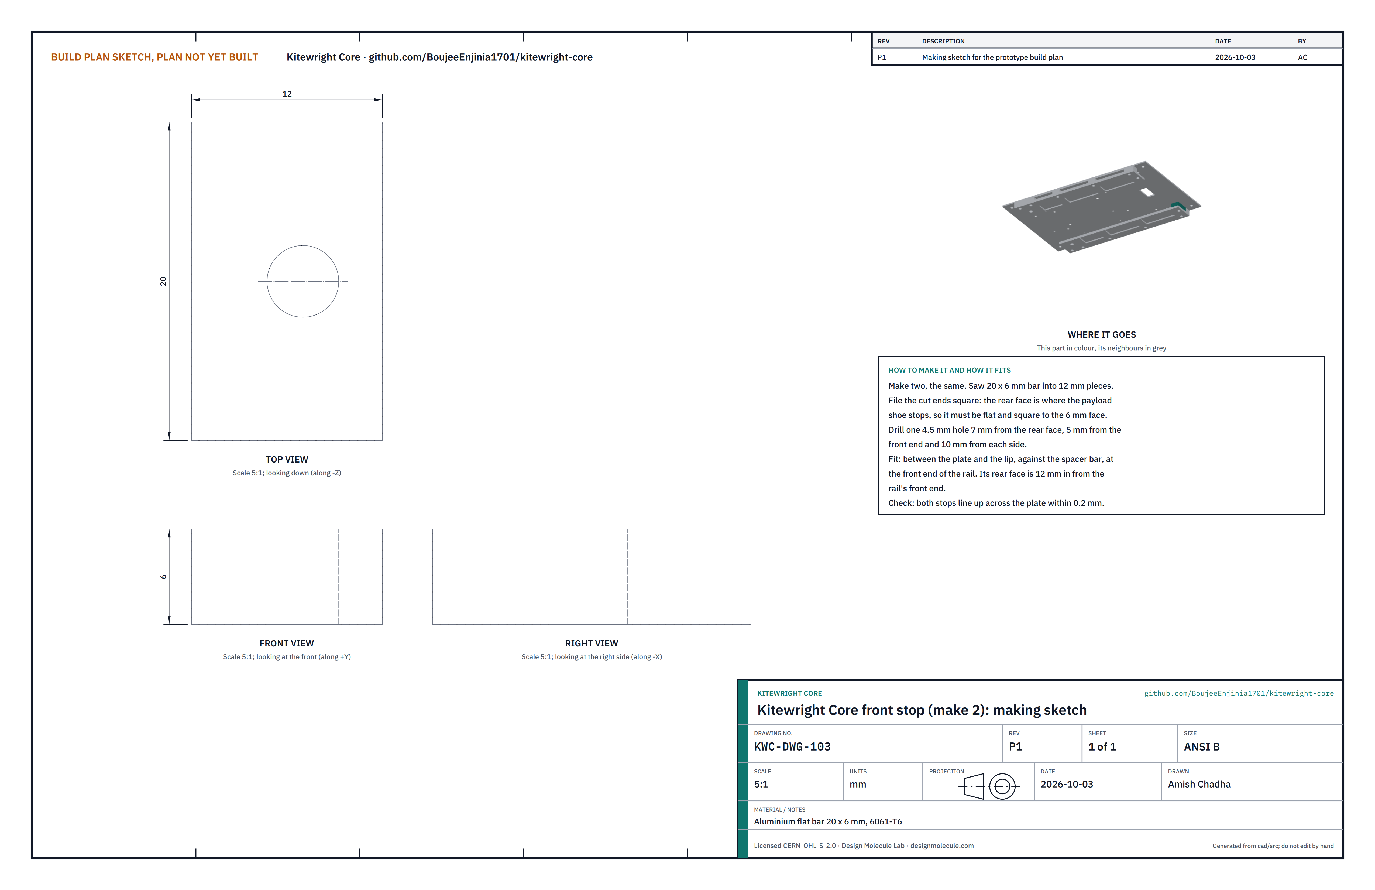
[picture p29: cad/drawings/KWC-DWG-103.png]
Figure 4. Front stop making sketch


*Figure 4. Making sketch KWC-DWG-103.*

**What it is and what it is made from.** A small block that stops the shoe at the front end of the rail: 20 x 6 mm 6061-T6 bar, 12 mm long.

**How to make it.**

1. Saw two pieces 12 mm long and file the cut ends flat and square: the rear face is where the shoe stops. Have them clear-anodised with the spacer bars.
2. Drill one 4.5 mm hole, 7 mm from the rear face, 5 mm from the front end and 10 mm from each side.

**How it fits the parts next to it.** It sits between the plate and the lip, against the inner edge of the spacer bar, with its front end level with the rail's front end. The rail's stop screw clamps it (Figure 15).

**Check before moving on.** With both stops fitted loosely, their rear faces line up across the plate within 0.2 mm.

### 3.4 Rail lips with wear tape (make a left and a right)

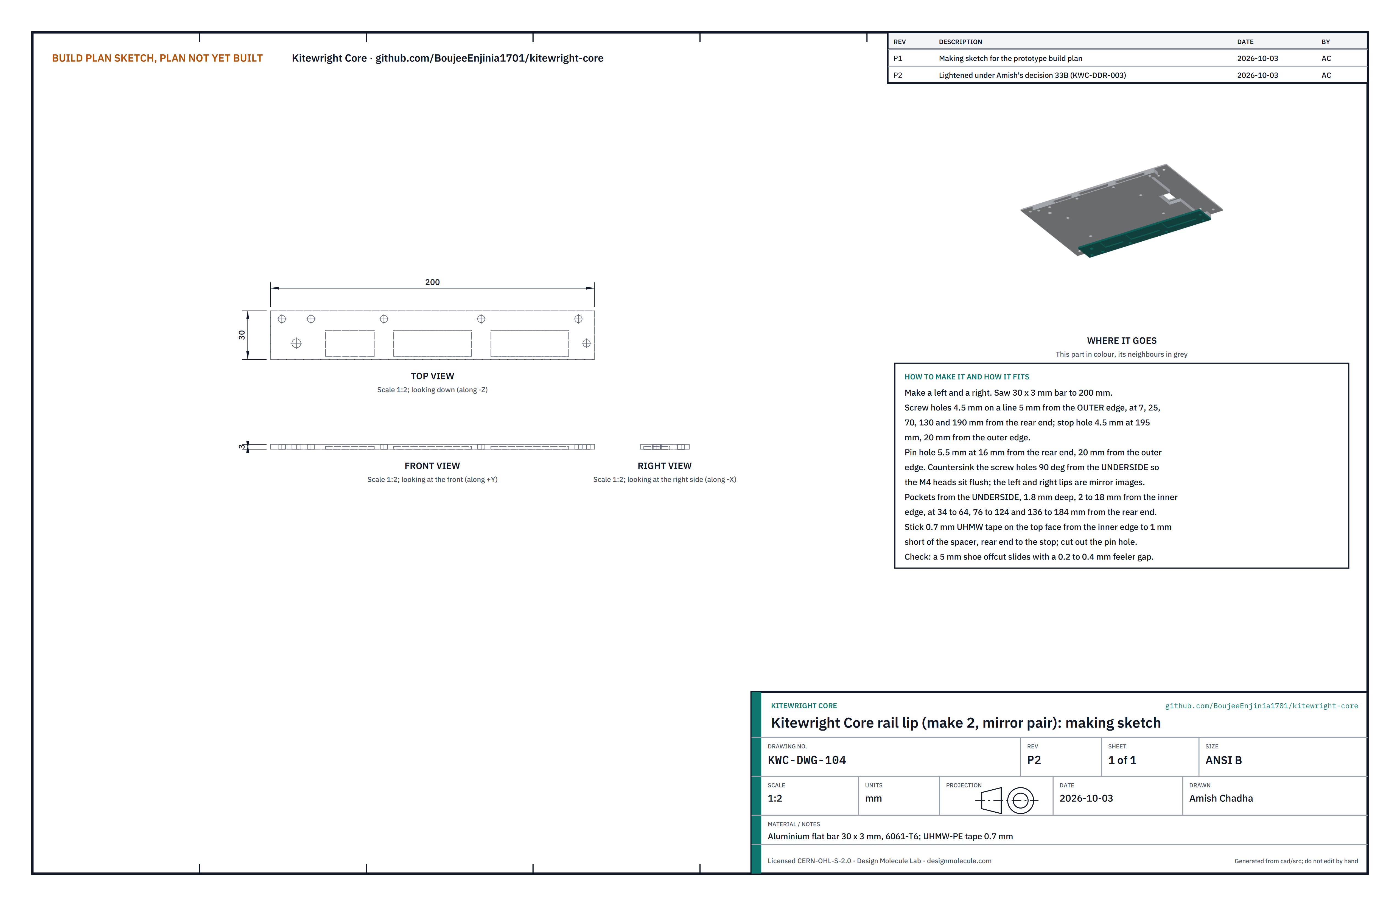
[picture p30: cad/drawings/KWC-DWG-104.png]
Figure 5. Rail lip making sketch


*Figure 5. Making sketch KWC-DWG-104, Rev P2.*

**What it is and what it is made from.** The bar the shoe's edge rides on: 30 x 3 mm 6061-T6 flat bar, 200 mm long, with 0.7 mm UHMW-PE tape on top.

**How to make it.**

1. Saw two pieces 200 mm long.
2. Drill the five screw holes 4.5 mm on a line 5 mm from the outer edge, at 7, 25, 70, 130 and 190 mm from the rear end, and the stop hole 4.5 mm at 195 mm, 20 mm from the outer edge.
3. Drill the pin hole 5.5 mm, 16 mm from the rear end and 20 mm from the outer edge.
4. Countersink the screw and stop holes 90° from the underside, deep enough that an M4 countersunk head sits flush. The left and right lips are mirror images: lay them side by side, outer edges outward, before countersinking.
5. Mill three pockets into the underside, 1.8 mm deep (1.2 mm of metal left), from 2 mm to 18 mm in from the inner edge, at 34 to 64 mm, 76 to 124 mm and 136 to 184 mm from the rear end. They keep clear of the screw line, the pin hole and the pin block.
6. Stick UHMW-PE tape on the top face from the inner edge to 1 mm short of the spacer bar's line, from the rear end to the front stop. Cut out the pin hole with a sharp knife.

**How it fits the parts next to it.** The tape faces up toward the plate. The shoe's edge overlaps the lip by 19 mm and rides on the tape, with 0.3 mm between the shoe and the plate (Figure 12).

**Check before moving on.** After step 1 of section 4, a 5 mm offcut of the shoe plate slides between lip and plate along the whole rail, with a 0.2 to 0.4 mm feeler gauge fitting above it.

### 3.5 Pin blocks (make 2)

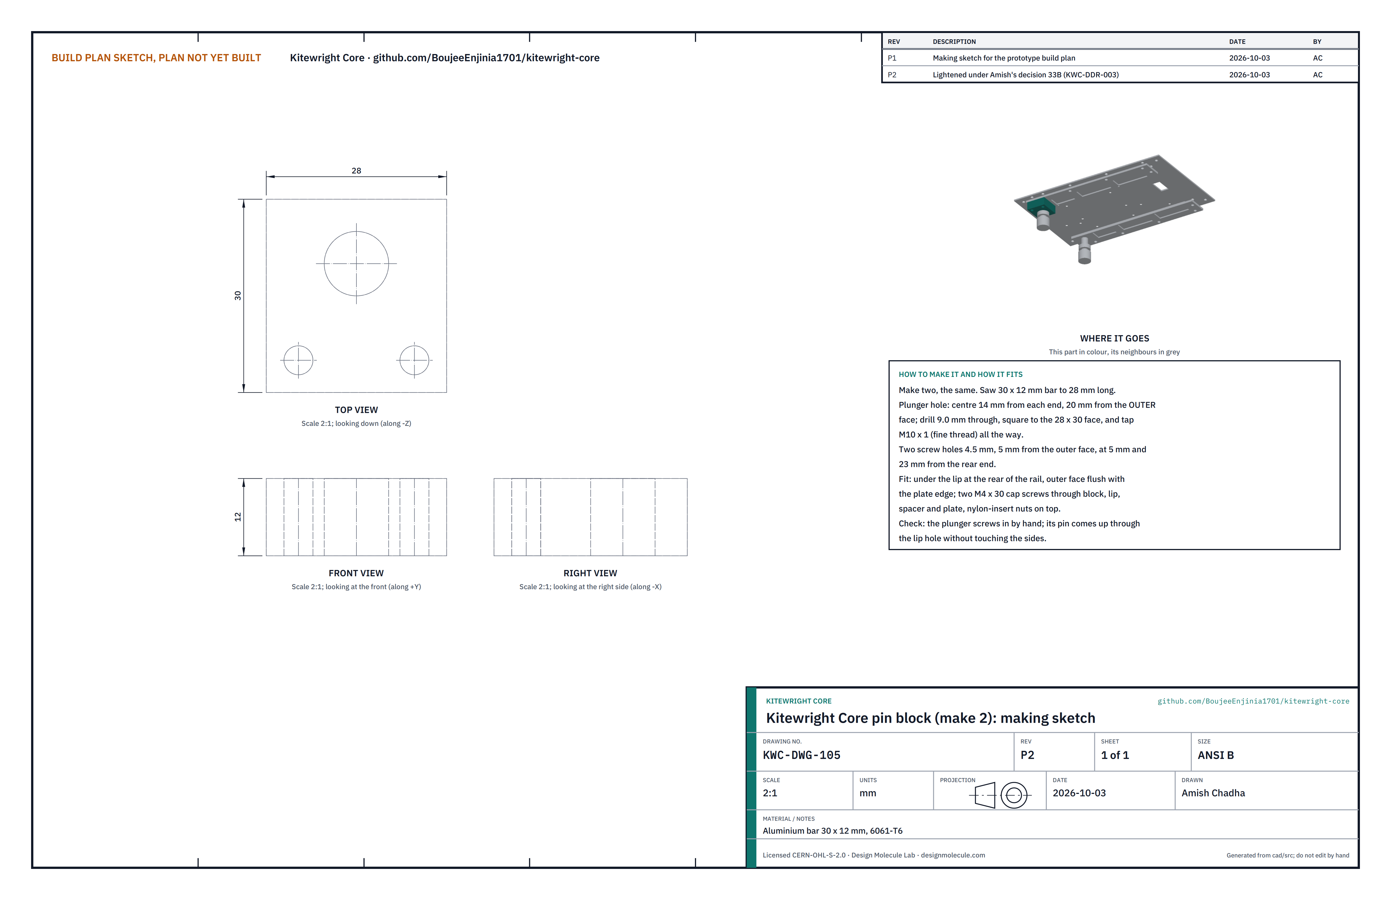
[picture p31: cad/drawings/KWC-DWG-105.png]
Figure 6. Pin block making sketch


*Figure 6. Making sketch KWC-DWG-105, Rev P2.*

**What it is and what it is made from.** The threaded block that holds a locking pin under the lip: 30 x 12 mm 6061-T6 bar, 28 mm long (12 mm of M10 x 1 thread holds the plunger).

**How to make it.**

1. Saw two pieces 28 mm long.
2. Mark the plunger hole 14 mm from each end and 20 mm from the outer face. Drill it 9.0 mm through, square to the 28 x 30 face, and tap M10 x 1 (fine thread) all the way.
3. Drill two 4.5 mm screw holes 5 mm from the outer face, at 5 and 23 mm from the rear end.

**How it fits the parts next to it.** The block sits under the lip at the rear of the rail with its outer face flush with the plate's edge; two M4 x 30 cap screws pass up through block, lip, spacer bar and plate into nylon-insert nuts on washers. The plunger screws up into it from below; its pin passes up through the lip and into the shoe (Figure 14).

**Check before moving on.** The plunger screws in by hand, and its pin comes up through the lip hole without touching the sides.

### 3.6 Payload shoe

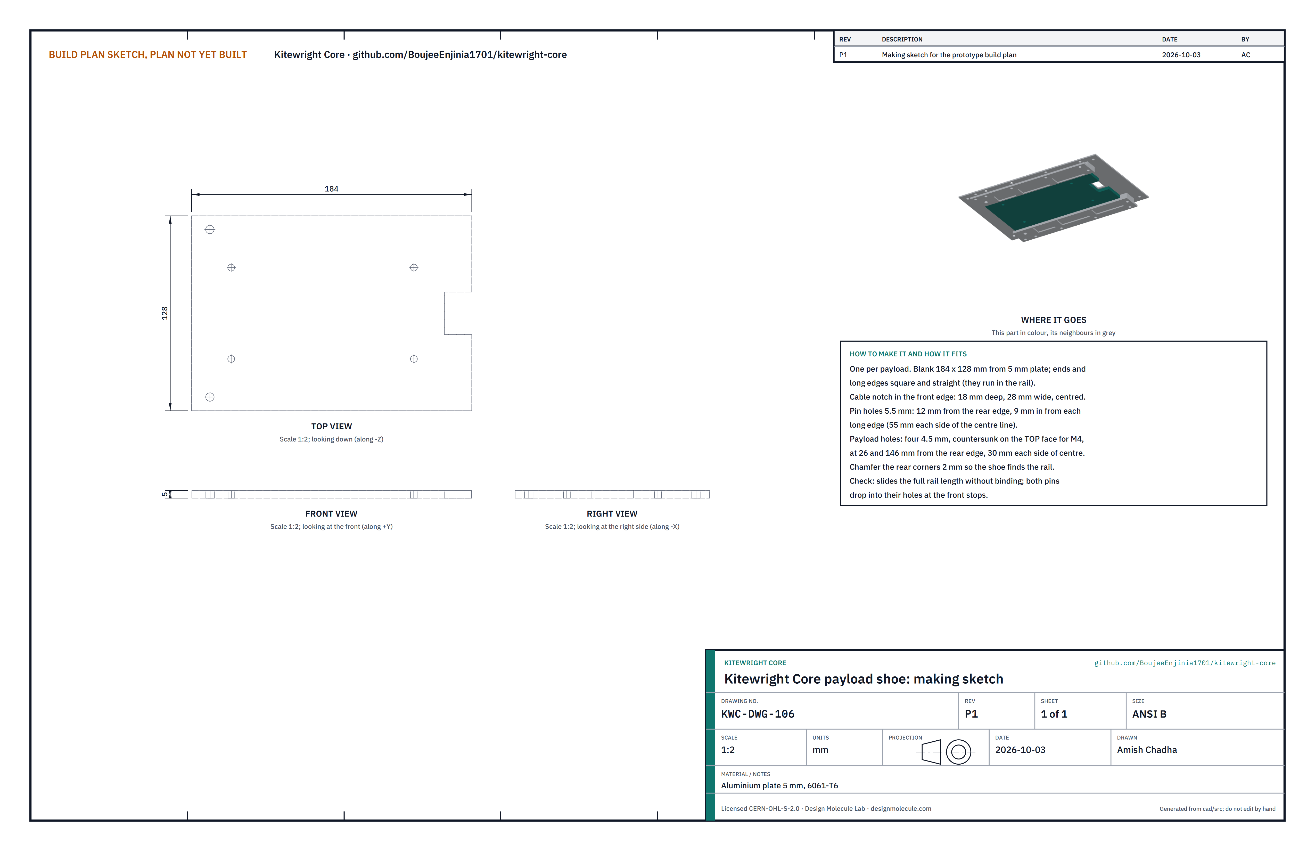
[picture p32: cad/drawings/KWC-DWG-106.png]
Figure 7. Payload shoe making sketch


*Figure 7. Making sketch KWC-DWG-106.*

**What it is and what it is made from.** The plate every payload carries on its top: 184 x 128 mm, cut from 5 mm 6061-T6 plate. The core kit carries one; each payload maker makes their own to this sketch.

**How to make it.**

1. Cut the blank 184 x 128 mm. The long edges and the front edge run in the rail and against the stops: make them straight and square.
2. Cut the cable notch in the middle of the front edge, 18 mm deep and 28 mm wide.
3. Drill the two pin holes 5.5 mm, 12 mm from the rear edge and 9 mm in from each long edge.
4. Drill four 4.5 mm payload holes at 26 and 146 mm from the rear edge, 30 mm each side of the centre line, and countersink them from the top so the screw heads sit flush.
5. Chamfer the rear corners 2 mm so the shoe finds the rail.

**How it fits the parts next to it.** It slides in from the rear between the plate and the lips until its front edge meets the front stops; both pins then rise into its holes (Figures 14 and 15). The payload bolts to its underside with four M4 countersunk screws from the top.

**Check before moving on.** In section 4, step 10: it slides the full rail without binding, and both pins drop into their holes at the stops.

### 3.7 Lid

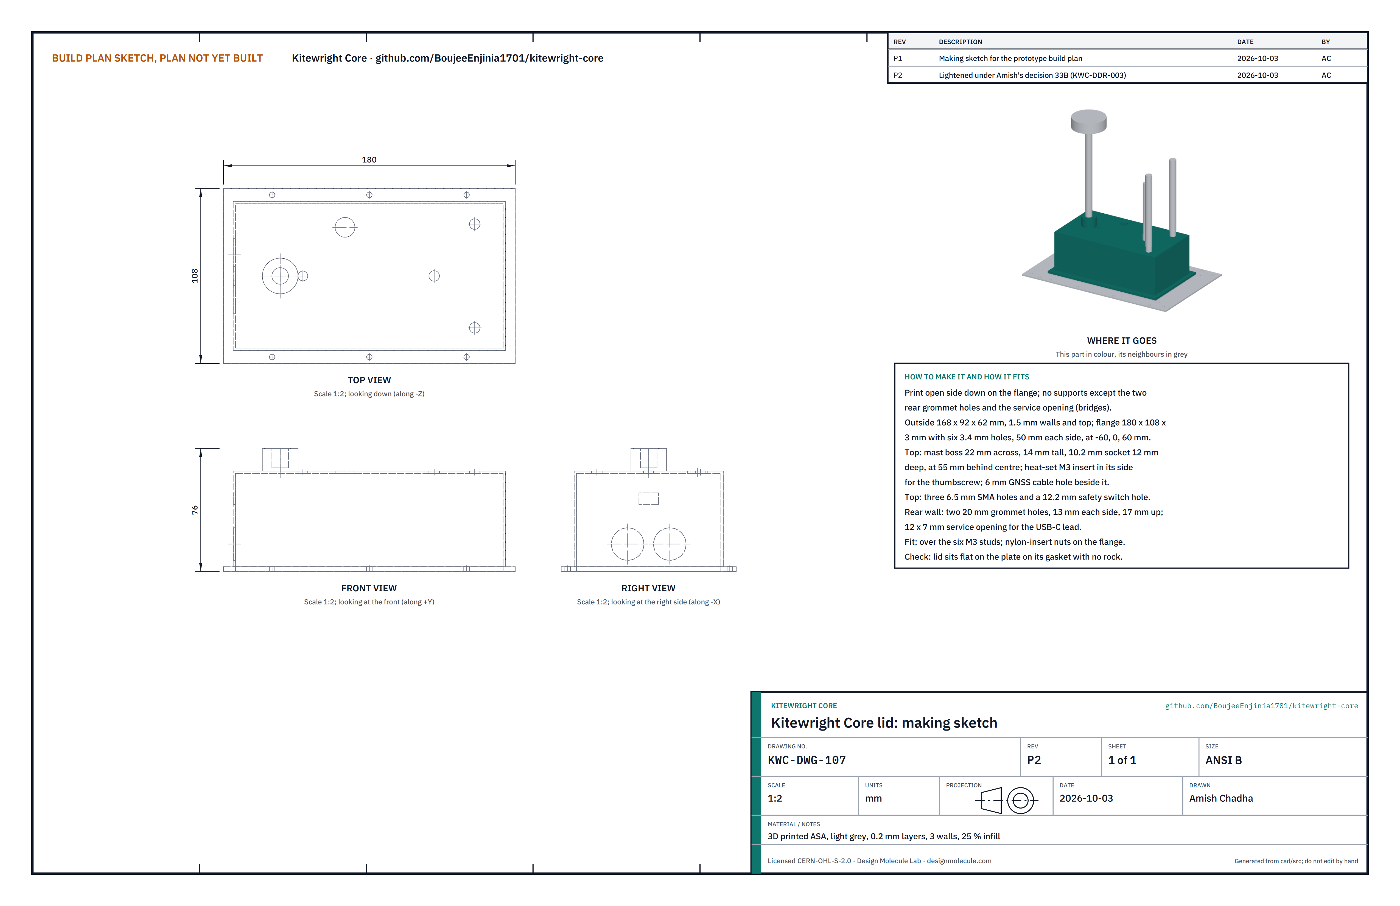
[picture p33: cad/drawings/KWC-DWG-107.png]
Figure 8. Lid making sketch


*Figure 8. Making sketch KWC-DWG-107, Rev P2.*

**What it is and what it is made from.** The cover over the avionics, printed in light grey ASA: 168 x 92 x 62 mm outside with 1.5 mm walls and top and a 180 x 108 x 3 mm flange.

**How to make it.**

1. Print it open side down on the flange, 0.2 mm layers, three walls (solid 1.5 mm), 25 % infill, supports only under the rear grommet holes and the service opening.
2. Check the six 3.4 mm flange holes, the 10.2 mm mast socket (12 mm deep in the 22 mm boss, 55 mm behind the centre), the 6 mm GNSS cable hole beside it, the three 6.5 mm antenna holes and the 12.2 mm switch hole in the top, and the two 20 mm grommet holes (13 mm each side, 17 mm up) and the 12 x 7 mm service opening in the rear wall. Clear them with a drill of the same size.
3. Melt an M3 heat-set insert into the side of the mast boss for the thumbscrew.
4. Cut the 1 mm foam gasket to the flange outline, with six 6 mm holes at the screws.

**How it fits the parts next to it.** The lid stands on the gasket on the plate over six M3 studs (countersunk screws pushed up from below the plate) and is held by six M3 nylon-insert nuts on its flange (Figure 23). It rises through the frame deck's opening, so it can be lifted off from above with the core in the frame.

**Check before moving on.** The lid sits flat on its gasket with no rock, and the flight controller, once fitted, clears its top by at least 5 mm.

### 3.8 Damping plate

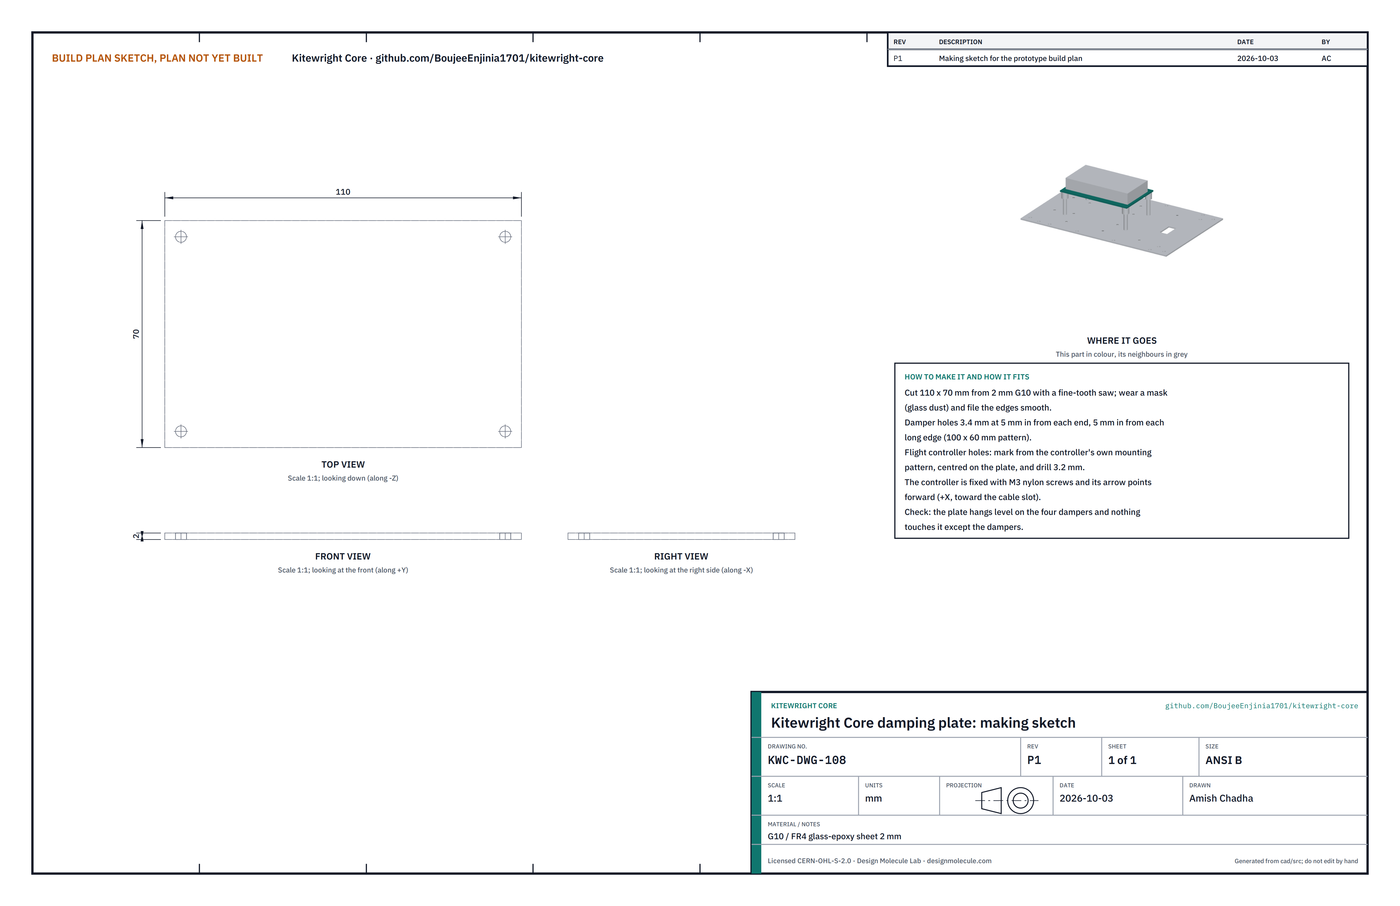
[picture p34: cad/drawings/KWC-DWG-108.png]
Figure 9. Damping plate making sketch


*Figure 9. Making sketch KWC-DWG-108.*

**What it is and what it is made from.** The plate the flight controller sits on: 110 x 70 mm of 2 mm G10 glass-epoxy sheet.

**How to make it.**

1. Cut 110 x 70 mm with a fine-tooth saw, wet or under extraction, and file the edges smooth.
2. Drill four 3.4 mm damper holes 5 mm in from each end and each long edge (a 100 x 60 mm pattern).
3. Mark the flight controller's own mounting pattern, centred, and drill 3.2 mm.

**How it fits the parts next to it.** It rests on the four silicone dampers, which sit on the tall standoffs; the controller is fixed to it with M3 nylon screws, its arrow pointing forward (Figure 18).

**Check before moving on.** It hangs level on the dampers and touches nothing else.

### 3.9 Strain-relief bar

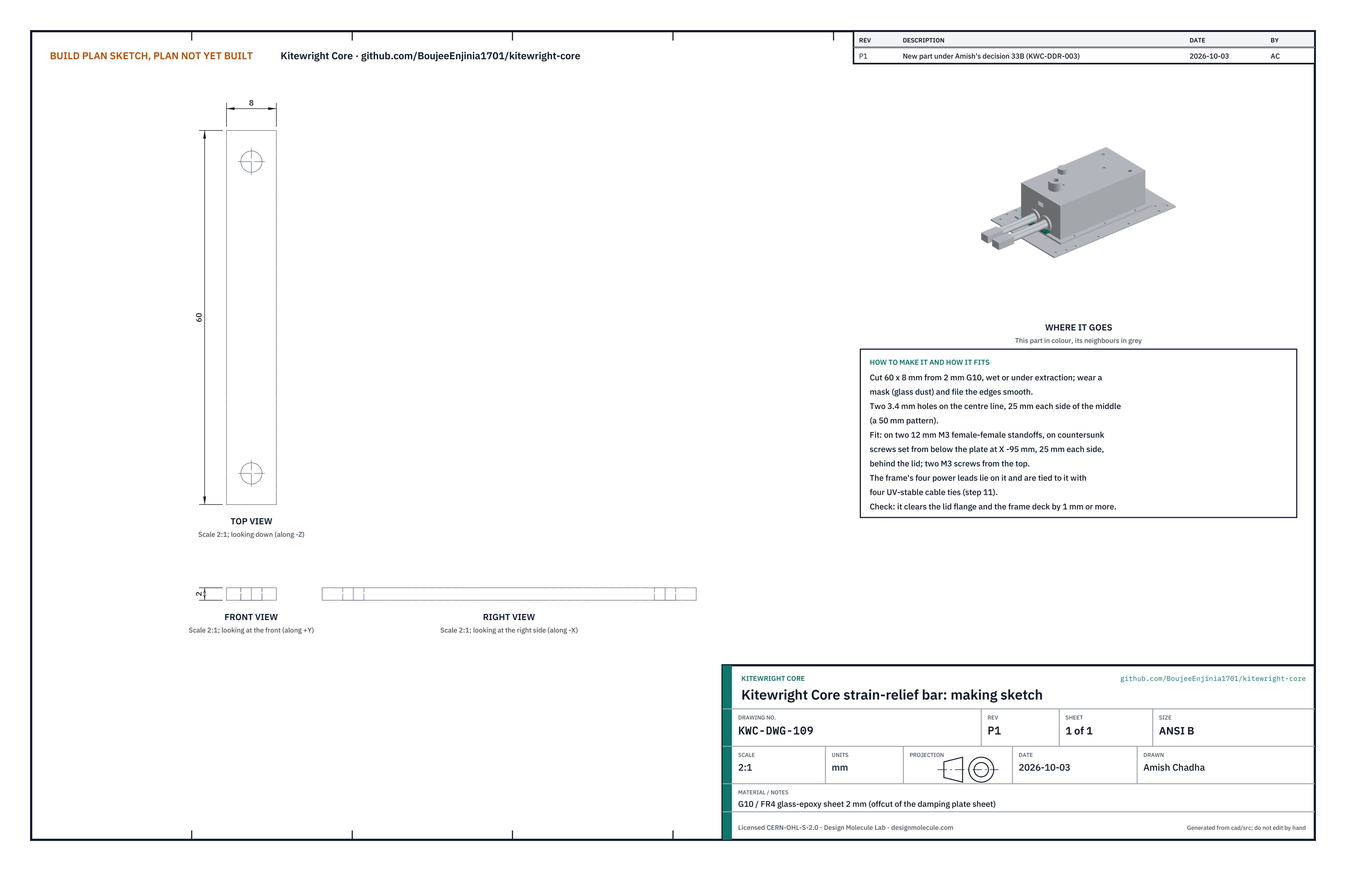
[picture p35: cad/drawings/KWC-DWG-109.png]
Figure 10. Strain-relief bar making sketch


*Figure 10. Making sketch KWC-DWG-109 (new under decision 33B).*

**What it is and what it is made from.** A small bar behind the lid that the frame's four power leads are tied to, so a tug on a lead never reaches the solder joints inside: 60 x 8 mm of 2 mm G10, from the damping plate's sheet.

**How to make it.**

1. Cut 60 x 8 mm, wet or under extraction, and file the edges smooth.
2. Drill two 3.4 mm holes on the centre line, 25 mm each side of the middle.

**How it fits the parts next to it.** It sits on two 12 mm M3 female-female standoffs, which sit on countersunk screws pushed up from below the plate 95 mm behind the centre and 25 mm each side. The leads lie on it and are tied to it with cable ties (step 11).

**Check before moving on.** It clears the lid flange and the frame deck by 1 mm or more.

### 3.10 Bought components

*Table 2. Bought components and what to do to them.*

| Component | What to buy (specification) | What to do to it |
| --- | --- | --- |
| Corner spacers (4) | Aluminium round spacers 12 mm OD x 8 mm, M4 clearance, anodised | Nothing |
| Locking pins (2) | Stainless indexing plungers, M10 x 1, 5 mm hardened pin, at least 9 mm stroke, pull knob with a rest (lock-out) position, with jam nuts | Paint a red band round each pin just below the lip when the pin is withdrawn, so a withdrawn pin shows red |
| Countersunk M3 fixings (16) | Stainless M3 countersunk screws, ISO 10642, 8 to 12 mm; six M3 nylon-insert nuts and washers | Push up through the plate's countersinks with thread-locker (steps 3, 4, 7 and 9) |
| Standoffs (10) | M3 female-female aluminium, anodised: four 25 mm, four 8 mm, two 12 mm (strain-relief bar) | Nothing |
| Dampers (4) | Silicone grommet dampers for M3, about 10 mm tall, rated -40 °C | Choose hardness for the controller's mass |
| Flight controller | Pixhawk FMUv6X class with standard baseboard | Load released PX4 and the Kitewright parameter set |
| GNSS receiver and mast | Multi-band GNSS with compass; 10 mm OD carbon tube, 150 mm; M3 thumbscrew | Fix the receiver to the tube's top with its own mount |
| Power distribution board | 18 to 60 V, 200 A peak, two inputs, two outputs, Hall current sensor, about 80 x 50 mm | Nothing |
| Power modules | Digital power monitor with 5.3 V supply, backup 5.3 V supply, payload switch (60 V, 8 A) | Nothing |
| Telemetry radio, receiver, antennas | 900 MHz class radio pair, long-range control link receiver, three antennas and SMA bulkhead pigtails | Set the band and power for the country of use |
| DS-014 pigtail | 40-pin connector pair per DS-014, 0.3 m pigtail, cable clamp | Wire to the controller and payload switch per the pin table |
| Safety switch, grommets, harness, gasket sheet, fasteners | As in `bom/bom.csv` | Nothing |

## 4. Putting it together

### Step 1: rails onto the core plate

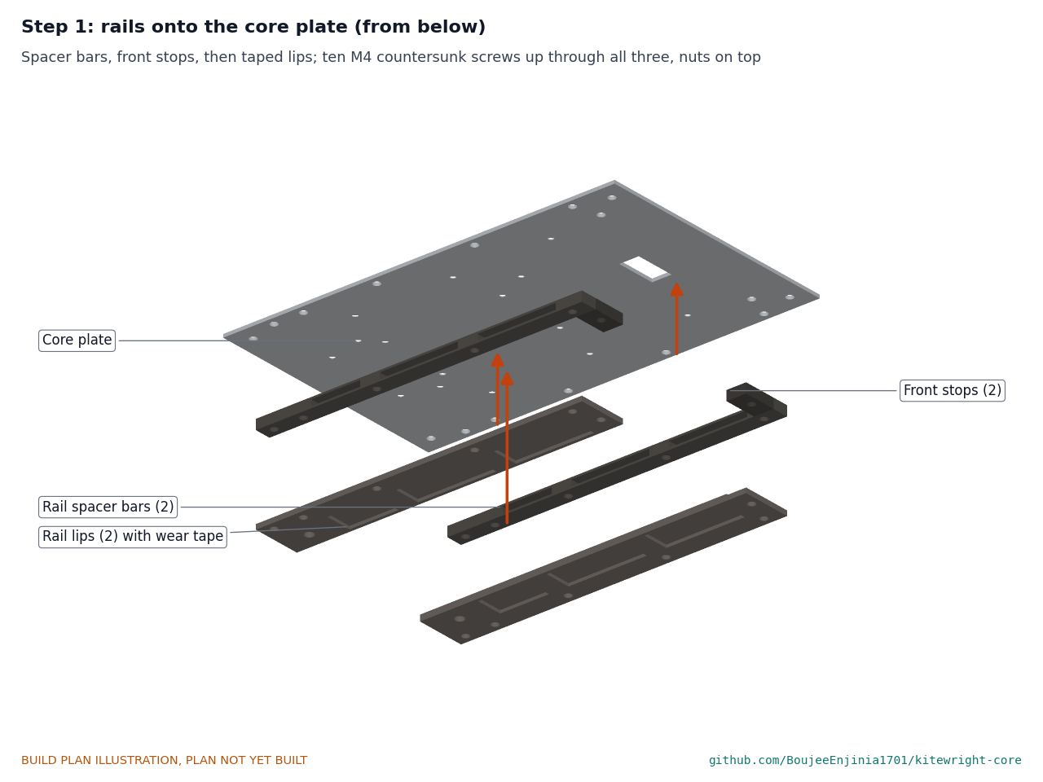
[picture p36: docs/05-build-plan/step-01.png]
Figure 11. Step 1


Turn the plate upside down. Lay the two spacer bars along its long edges, the front stops at the front against their inner edges, then the taped lips, outer edges flush. Push ten M4 x 16 countersunk screws up through lip, spacer bar and plate (and the two stop screws through lip, stop and plate), and fit nylon-insert nuts on washers on top. Use thread-locker; tighten to about 2 N·m, no more, so the washers do not crush the carbon. **Hold point:** do the shoe-offcut and feeler check of 3.4 now.

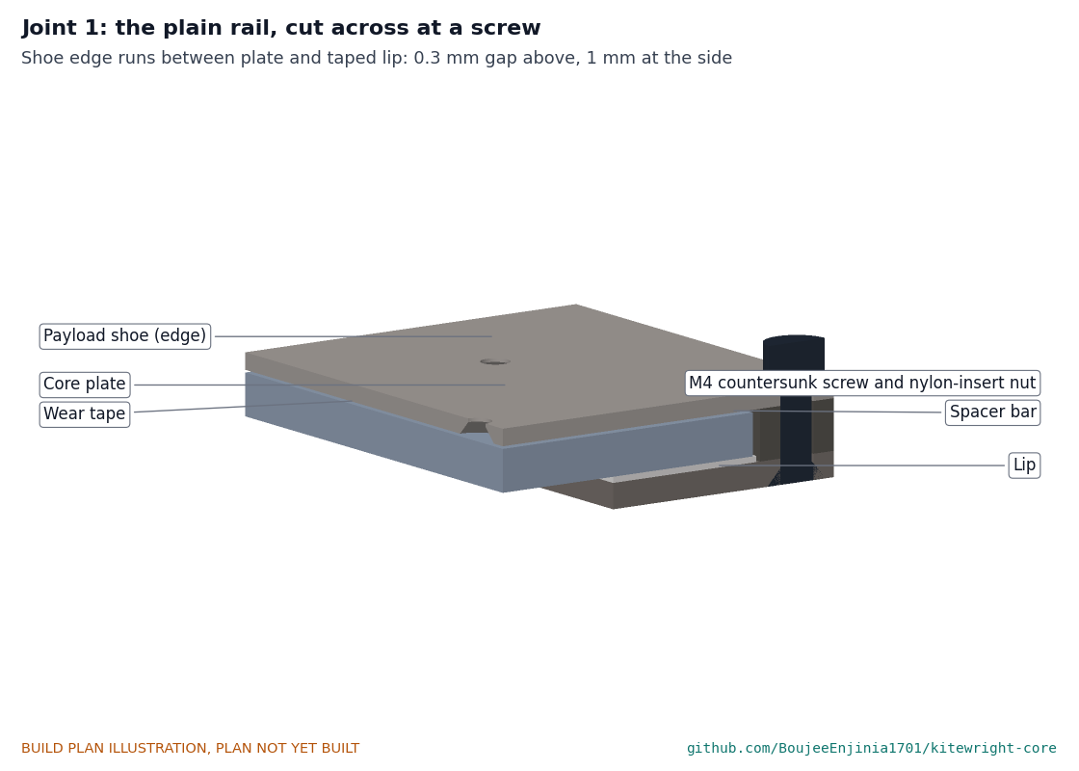
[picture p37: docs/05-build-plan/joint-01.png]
Figure 12. Joint 1


*Figure 12. The rail cut across at a screw: the shoe's edge runs on the taped lip, 0.3 mm under the plate.*

### Step 2: pin blocks and locking pins

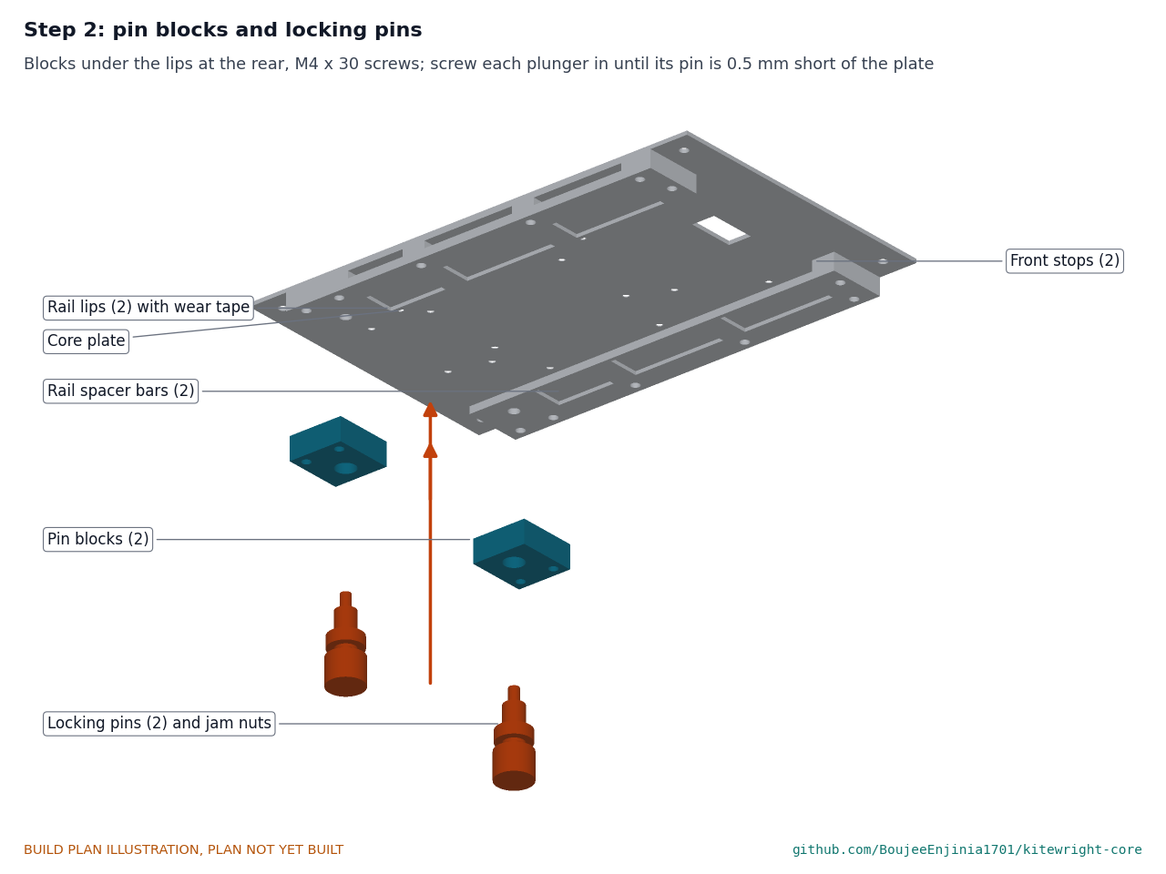
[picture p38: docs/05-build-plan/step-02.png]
Figure 13. Step 2


Fit each pin block under its lip at the rear with two M4 x 30 cap screws up through block, lip, spacer bar and plate, nuts on top. Screw a plunger up into each block until, released, its pin tip is 0.5 mm short of the plate; lock it with the jam nut.

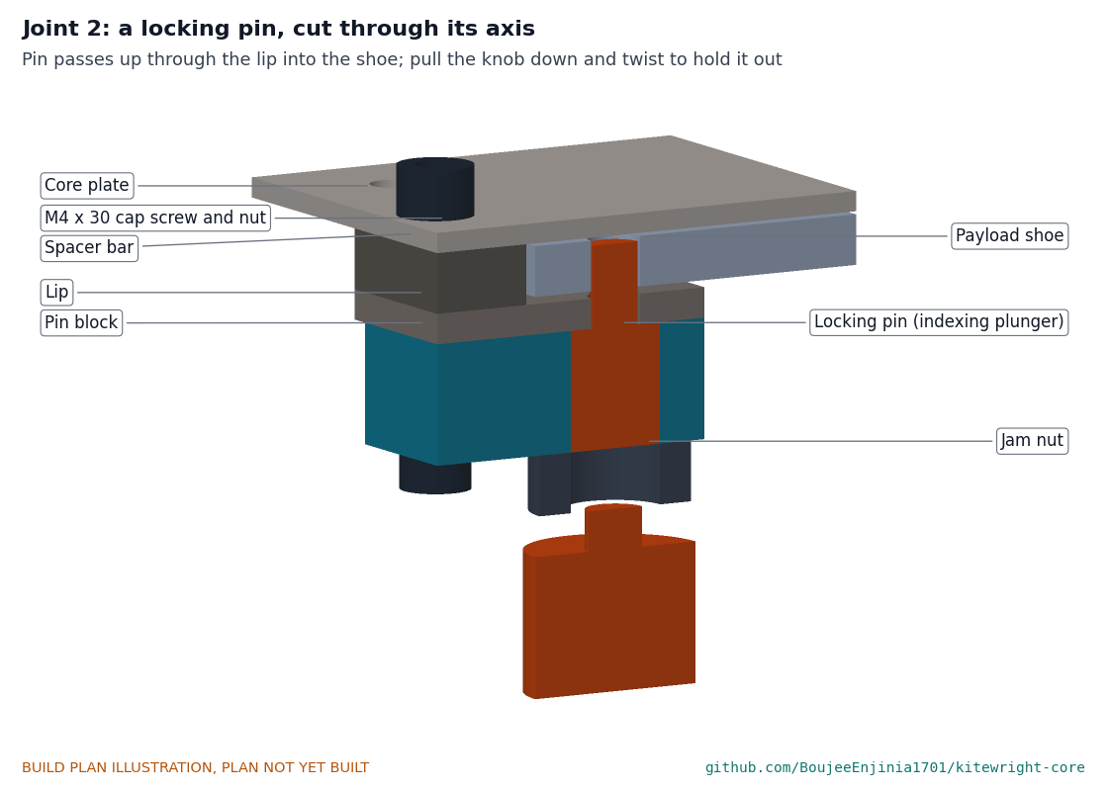
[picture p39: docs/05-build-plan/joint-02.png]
Figure 14. Joint 2


*Figure 14. A locking pin cut through its axis: the pin rises through the lip into the shoe.*

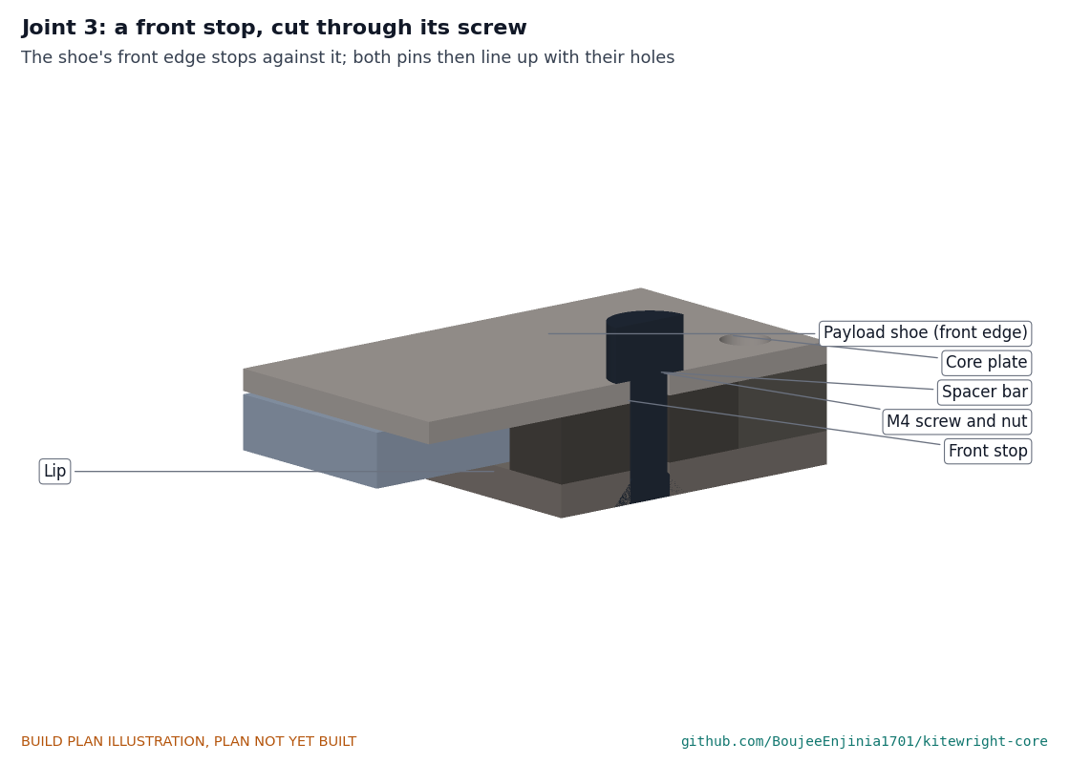
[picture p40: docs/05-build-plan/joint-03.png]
Figure 15. Joint 3


*Figure 15. A front stop, clamped between plate and lip by the stop screw.*

### Step 3: power board

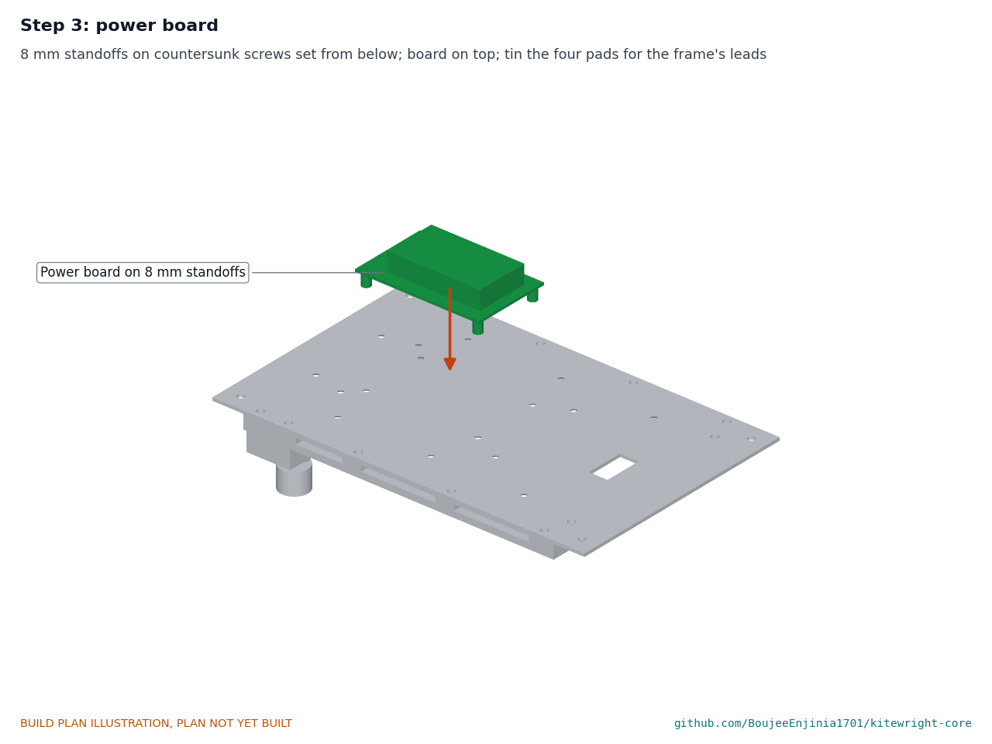
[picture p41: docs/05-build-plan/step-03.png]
Figure 16. Step 3


Turn the plate the right way up. Push four M3 countersunk screws up through the short-standoff countersinks with thread-locker, screw the four 8 mm standoffs onto them and fix the power board on top with M3 screws. Tin the board's four big pads (two pack inputs, two frame outputs); the frame's own leads are soldered to them in step 11.

### Step 4: flight controller on its dampers

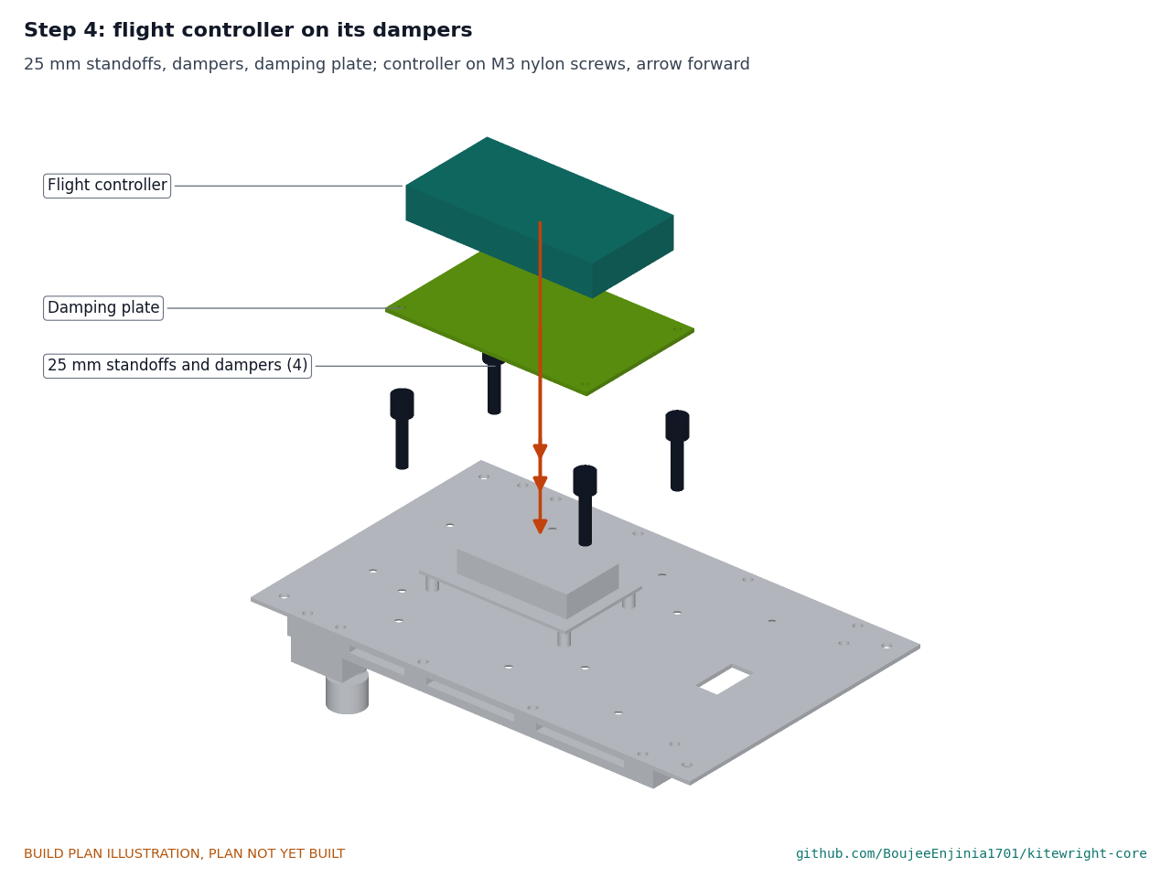
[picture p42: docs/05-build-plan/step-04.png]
Figure 17. Step 4


Push four M3 countersunk screws up through the tall-standoff countersinks with thread-locker and screw the four 25 mm standoffs onto them. Fit a damper on each, lay the damping plate on the dampers and fix it with M3 screws into the dampers. Fix the flight controller to the plate with M3 nylon screws, arrow forward.

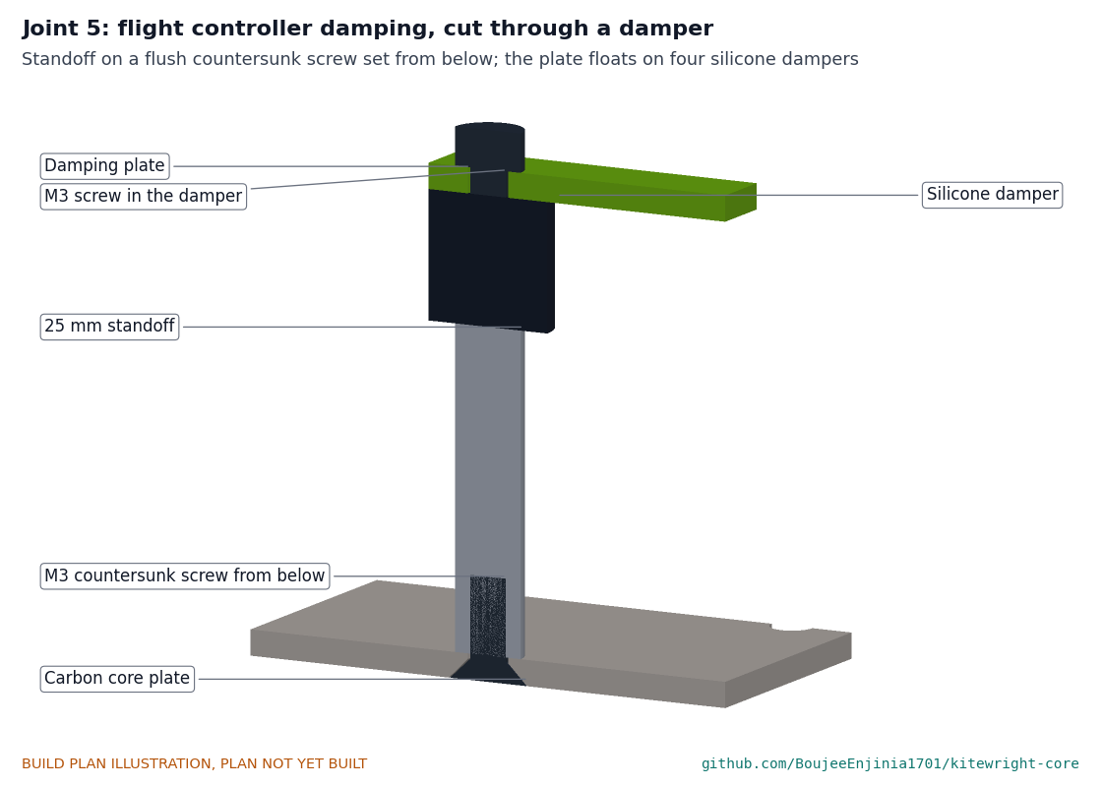
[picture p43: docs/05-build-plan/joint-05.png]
Figure 18. Joint 5


*Figure 18. Flight controller damping, cut through a damper.*

### Step 5: radio, power modules and receiver

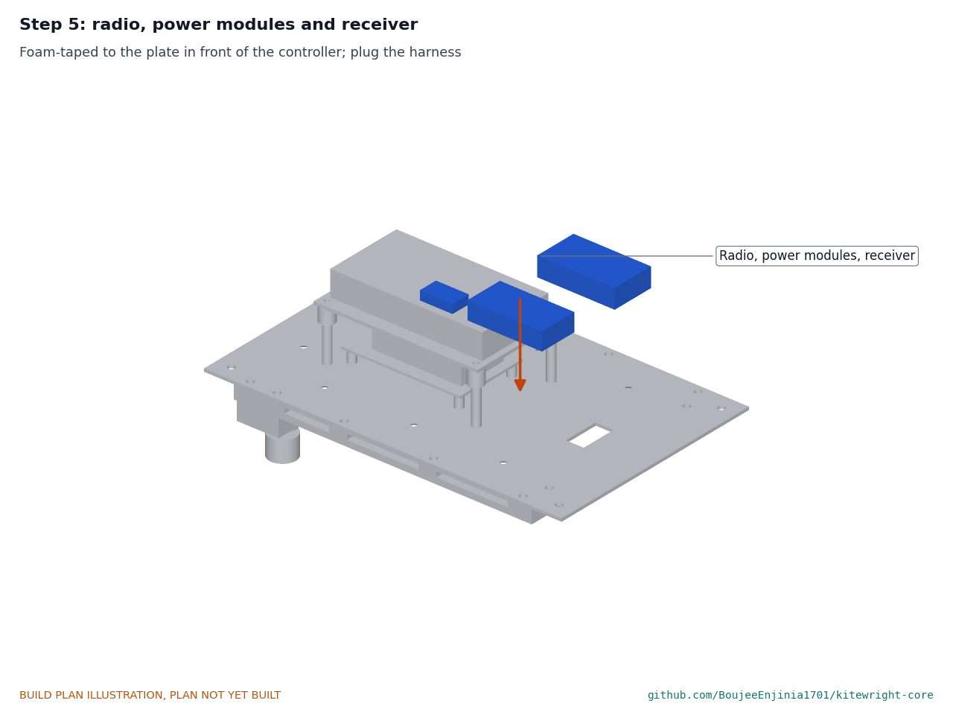
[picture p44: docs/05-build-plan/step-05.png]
Figure 19. Step 5


Stick the telemetry radio (left front), power modules (right front) and control link receiver (right, under the damping plate) to the plate with foam tape, at room temperature. Plug in the harness: power modules to the controller's two power inputs, radio to a telemetry port, receiver to the control input, power board current sensor to its input, payload switch enable to a spare output.

### Step 6: DS-014 pigtail

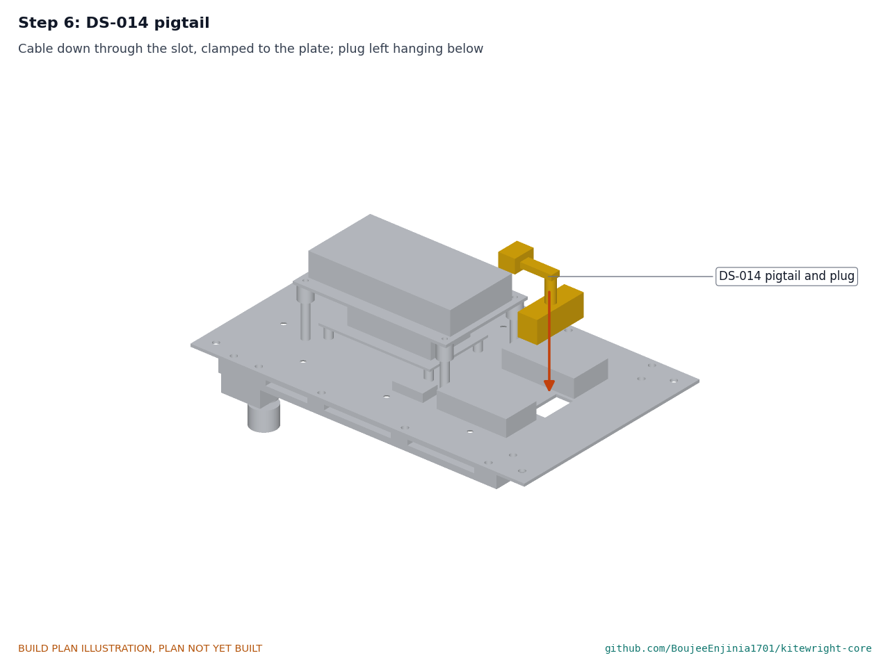
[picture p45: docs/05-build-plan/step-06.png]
Figure 20. Step 6


Pass the pigtail's plug down through the cable slot from above and clamp the cable to the plate just behind the slot. Wire its power pins to the payload switch and its data pins to the controller's Ethernet, CAN, serial and trigger ports, per the DS-014 pin table.

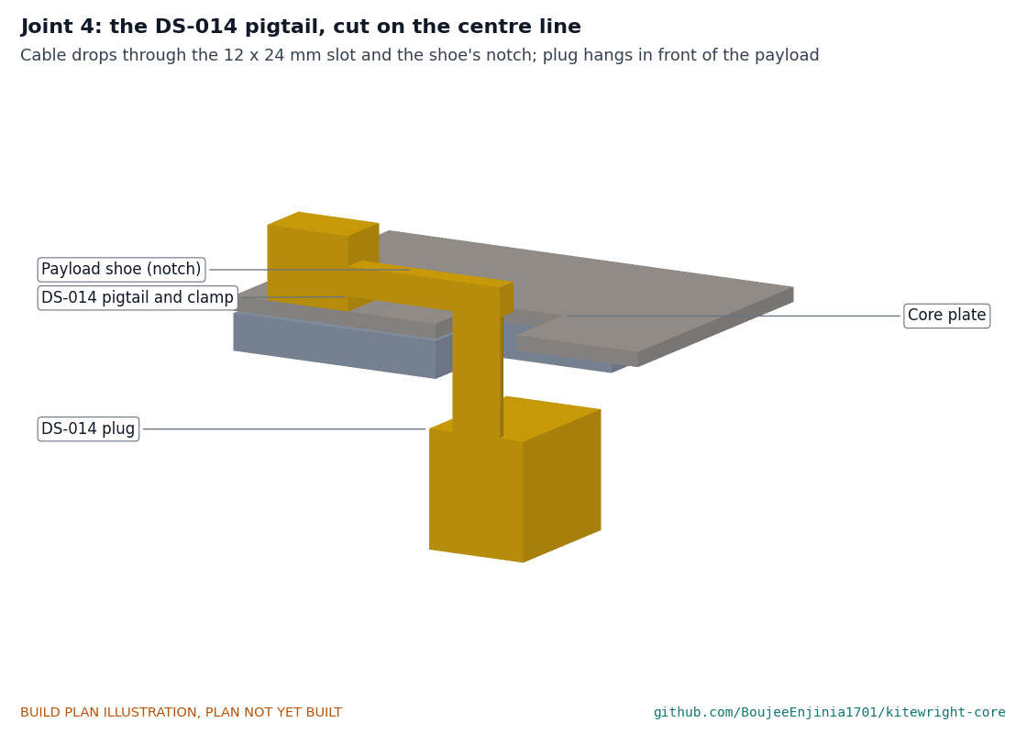
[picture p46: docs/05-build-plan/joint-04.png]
Figure 21. Joint 4


*Figure 21. The pigtail through the slot and the shoe's notch; the plug hangs in front of the payload.*

### Step 7: gasket and lid

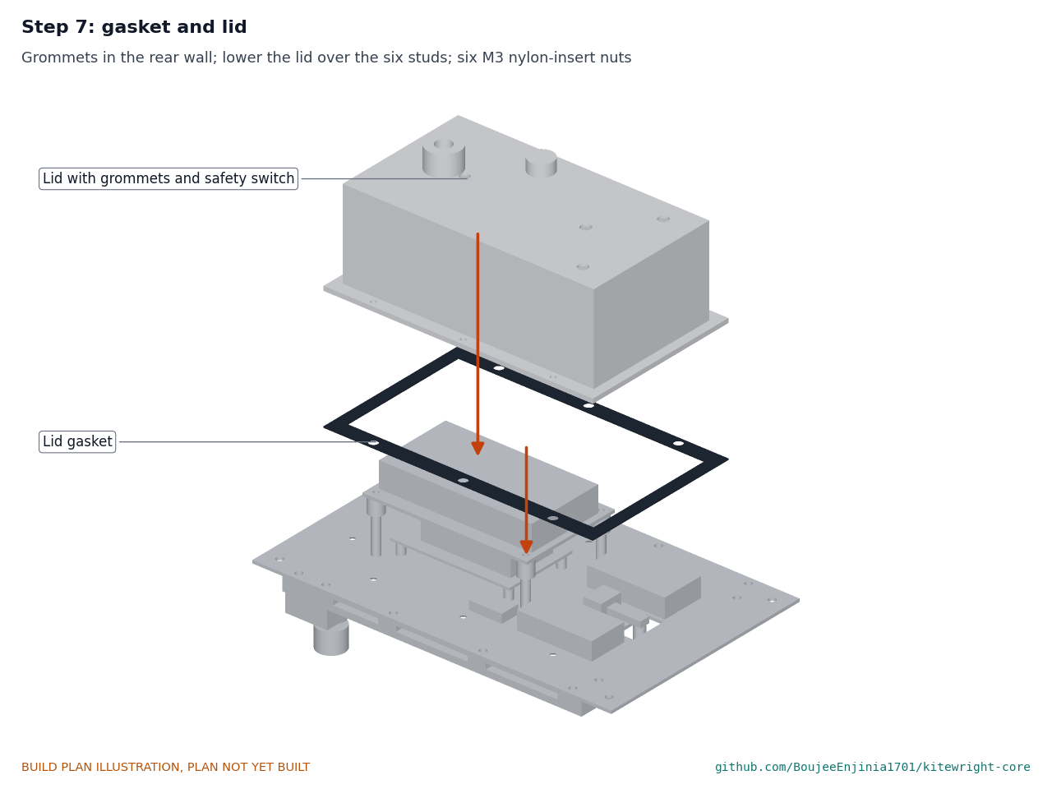
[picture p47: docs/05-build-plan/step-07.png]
Figure 22. Step 7


Push six M3 x 12 countersunk screws up through the flange countersinks with thread-locker: they are the lid's studs. Stick the gasket to the plate around the avionics. Fit the two grommets to the lid's rear wall. Lower the lid over the studs onto the gasket and fit six M3 nylon-insert nuts on washers, snug but not crushing the gasket.

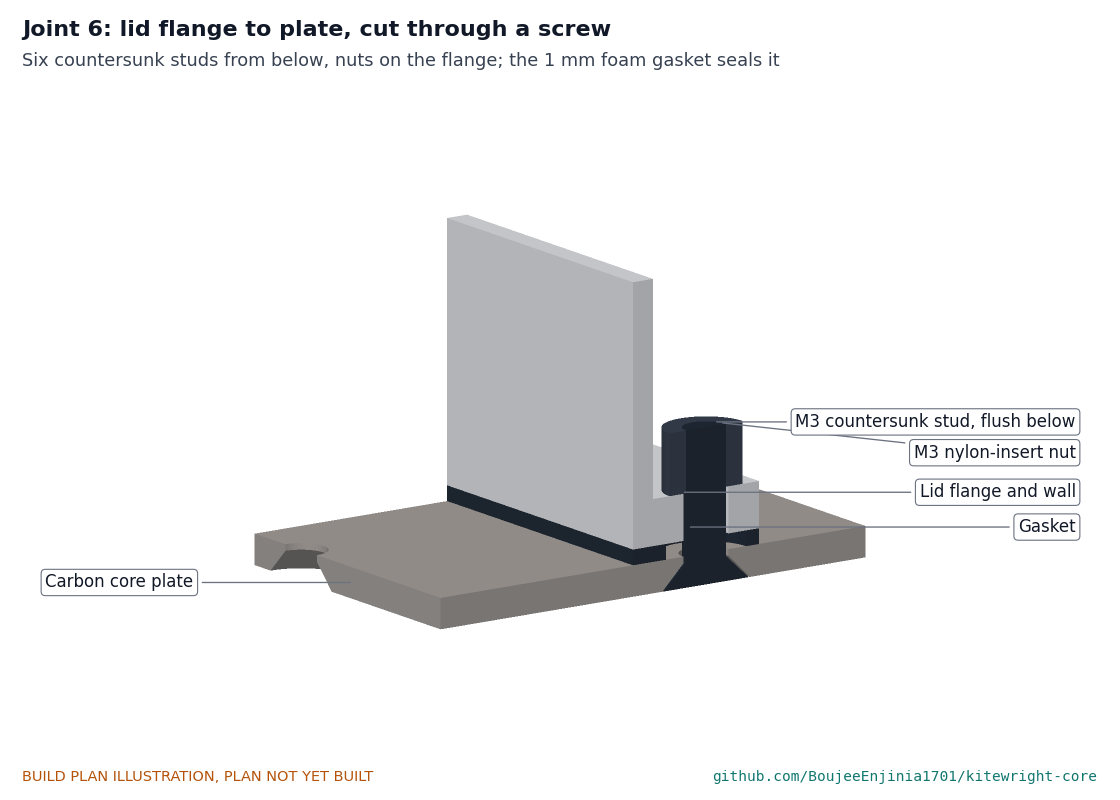
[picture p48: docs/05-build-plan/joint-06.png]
Figure 23. Joint 6


*Figure 23. Lid flange to plate: the flush countersunk stud, gasket and nut.*

### Step 8: antennas, GNSS mast and receiver

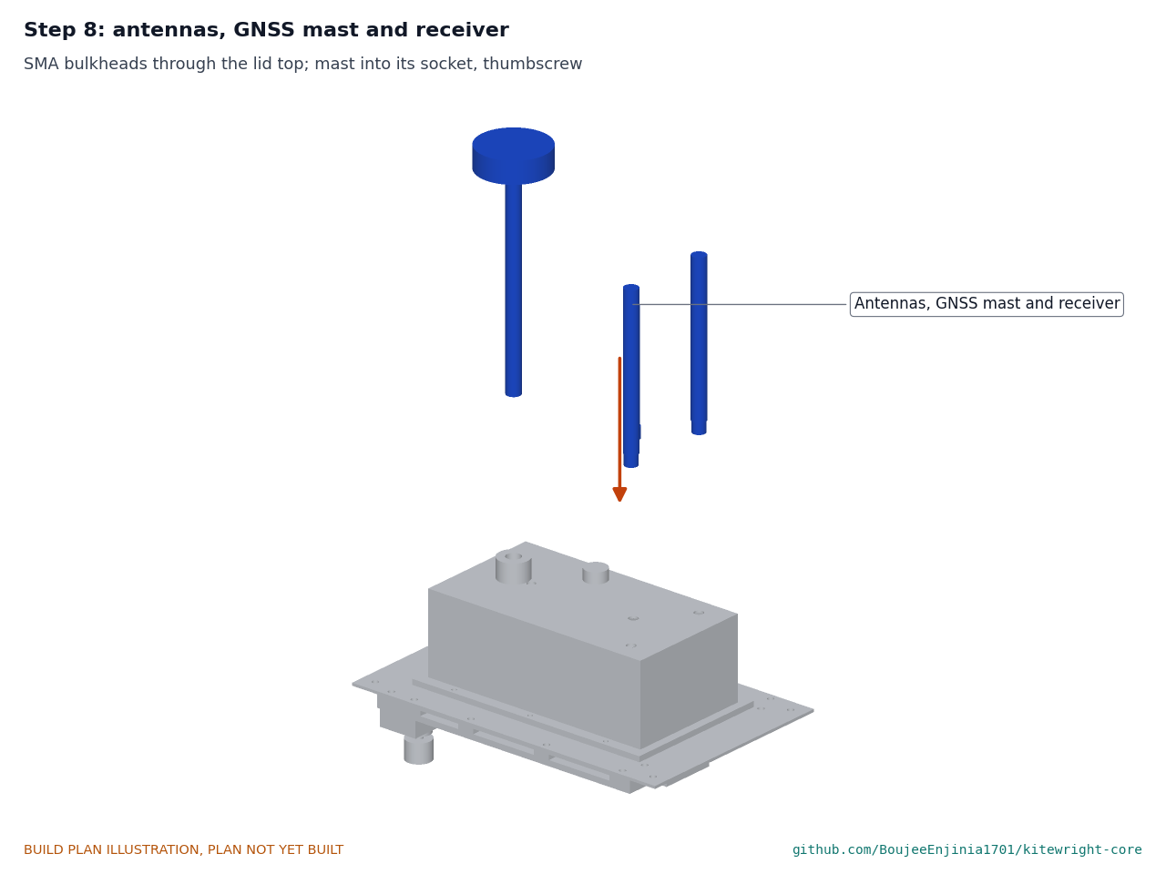
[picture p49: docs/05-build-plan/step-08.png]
Figure 24. Step 8


Fit the three SMA bulkheads through the lid top and screw on the antennas. Press the safety switch into its hole. Push the mast into its socket, lock it with the thumbscrew, and run the GNSS cable in through the hole beside the boss.

### Step 9: strain-relief bar

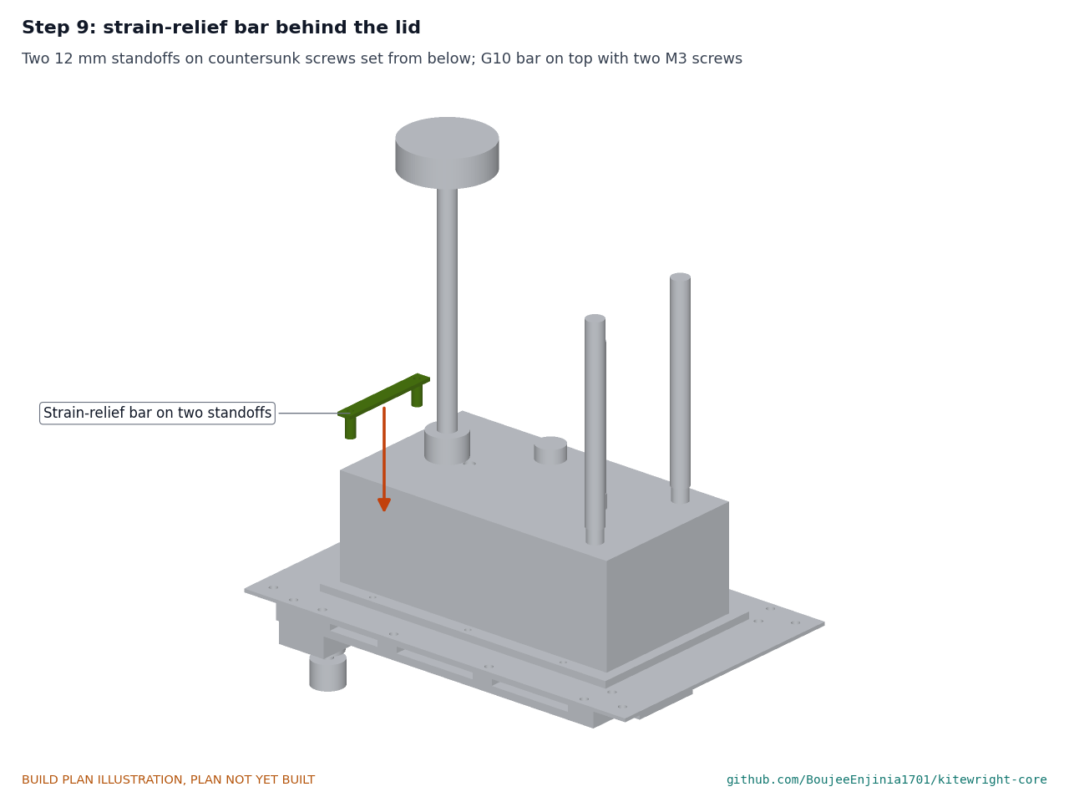
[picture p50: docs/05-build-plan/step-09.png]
Figure 25. Step 9


Push two M3 countersunk screws up through the countersinks behind the lid with thread-locker, screw the two 12 mm standoffs onto them, and fix the G10 bar on top with two M3 screws. The cable ties go on in step 11.

### Step 10: payload shoe in from the rear (payload swap)

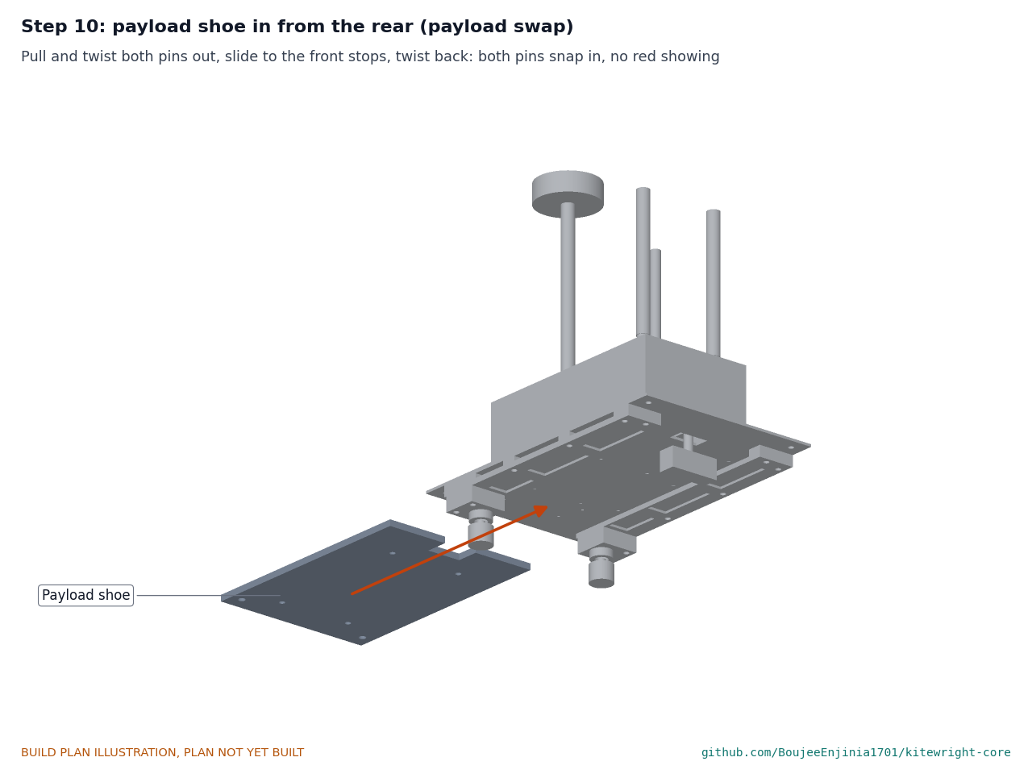
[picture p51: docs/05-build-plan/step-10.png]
Figure 26. Step 10


Pull both plunger knobs down and twist them to their rest. Slide the shoe into the rail from the rear until it meets the front stops. Twist both knobs back: the pins snap up into the shoe. Push the DS-014 plug into the payload's socket. **Hold point:** no red band shows on either pin, and a firm tug does not move the shoe.

### Step 11: into the frame

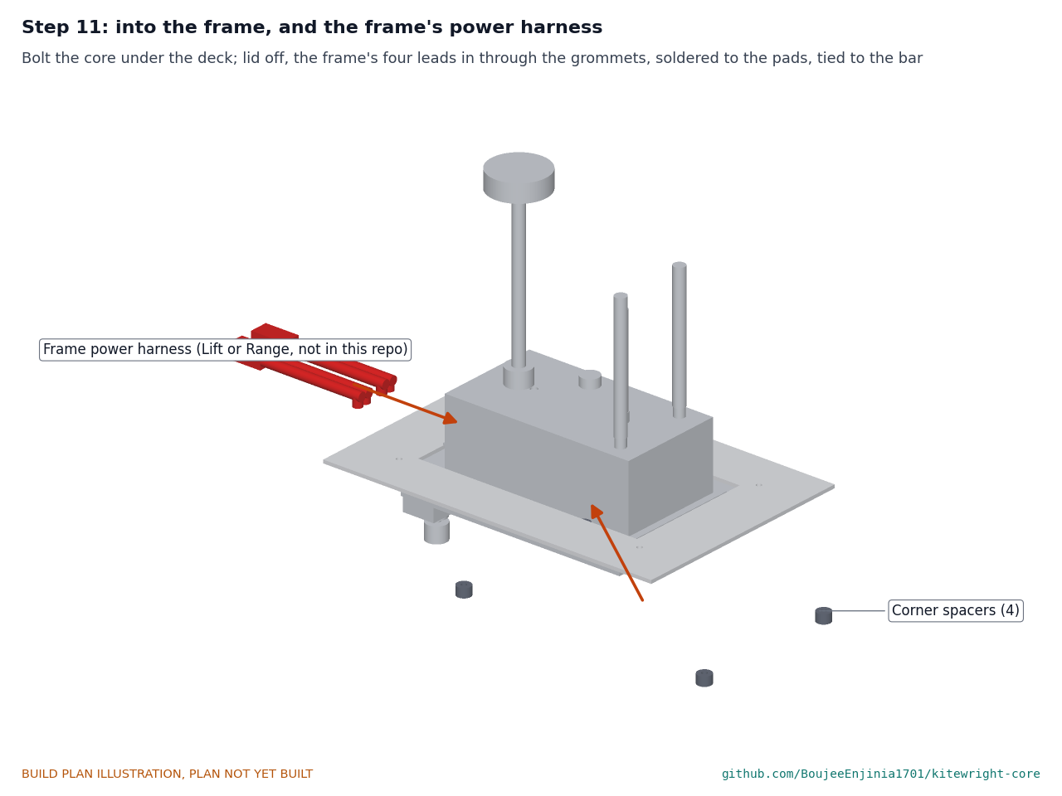
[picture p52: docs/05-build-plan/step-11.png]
Figure 27. Step 11


Put a corner spacer on each frame hole of the plate, lift the core so the lid passes up through the frame deck's opening, and fit four M4 bolts down through deck, spacers and plate with nylon-insert nuts on washers underneath.

Then fit the frame's power harness, which comes with Kitewright Lift or Range: four 8 AWG leads with AS150 plugs already on their far ends, inputs and outputs of opposite gender, labelled "PACK 1", "PACK 2", "FRAME A" and "FRAME B". Take the six nuts off and lift the lid off from above. Thread the leads in through the rear grommets, two per grommet, and solder each to its pad on the power board (pack inputs and frame outputs as the board marks them). Refit the lid. Tie the leads to the strain-relief bar with four cable ties, leaving a little slack between the bar and the grommets. Plug the frame's speed controller leads into the two frame outputs. To move the core to the other frame (R8 as restated on 2026-10-04, KWC-DDR-004), disconnect every pack, take the lid off, desolder the four leads, solder on the other frame's harness the same way and repeat safety stop 2; it takes about 30 min.

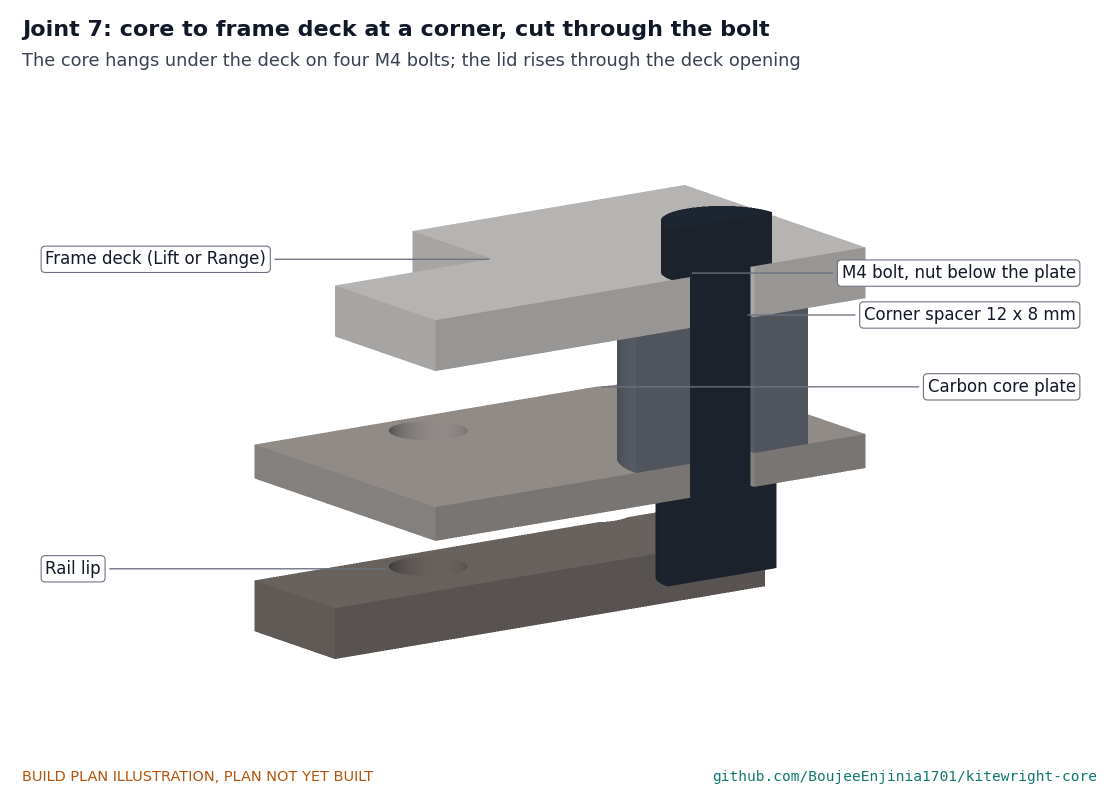
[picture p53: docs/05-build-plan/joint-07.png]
Figure 28. Joint 7


*Figure 28. Core to frame deck at a corner: the deck belongs to Kitewright Lift or Range.*

## 5. First checks

*Table 3. First checks; a TRL 4 test report records the results.*

| Check | Requirement | How | Pass when |
| --- | --- | --- | --- |
| Flush underside | R2 | Straight edge across the plate's underside after steps 3, 4, 7 and 9 | No countersunk head stands proud |
| Rail fit | R2, R3 | Slide the shoe the full rail length; feeler gauge above it | No binding; 0.2 to 0.4 mm gap; both pins drop in at the stops |
| Pin retention | R3 | Pull each pin to its rest and back; tug the shoe with one pin withdrawn | Each pin alone stops the shoe; red band shows only when withdrawn |
| Proof load | R3 | Hang 15 kg from the shoe for 1 min on the bench (core on a fixed stand, nobody beneath) | No permanent set, no slip |
| Payload swap | R2 | Timed swap with winter gloves, three people, three times each | 60 s or less, no tools |
| First power | R4, R5 | Bench supply at 24 V, current limit 1 A, no packs | Controller boots; both 5.3 V rails in range; no part warm to the touch |
| Payload power | R4 | Payload switch on into a 100 W load at 18 V and 50 V | Load holds 100 W; switch and pigtail stay below 60 °C |
| Cold boot | R5 | Soak the core at -20 °C for 2 h, then power from the bench supply | Boots and logs normally |
| Interface | R1, R8 | DS-014 continuity and a MAVLink payload heartbeat with a reference payload | Every pin in the table connected; payload recognised |
| Firmware | R10 | Load the released PX4 build and the parameter set | No source changes; parameters load |
| Mass | R9 | Weigh the core without the shoe, packs and frame harness | 1.0 kg or less (0.99 kg estimated) |

## 6. Safety stops

Work stops at each point below until what it says is true.

1. **Before first power.** Every solder joint inspected; no pack anywhere near the bench; the power board's inputs checked for shorts with a meter; the bench supply set to 24 V and 1 A.
2. **Before connecting a pack.** The bench checks of section 5 passed; the frame harness's inputs and outputs keyed by opposite-gender AS150 plugs and labelled; polarity checked at the plug with a meter; the pack warm enough to discharge (ColdCell reports at least 10 °C); a lithium fire plan, sand bucket and extinguisher at hand; the core on a non-flammable surface; nobody alone.
3. **Before loading the mount.** Both pins show no red band and the shoe passes the tug test; the core is held on a fixed stand, not in a frame; nobody under the load.
4. **Before fitting propellers or arming any frame.** That frame's own build plan safety stops apply; the core's safety switch works; failsafes for the altitude band are loaded.
5. **Before any flight with a payload.** Pin check and tug test done by a second person; the flight follows local rules and the site partner's permissions.

## 7. Tools, skills and workspace

- Hacksaw or bandsaw, files, deburring tool, square and scriber; pillar drill with 3.2, 3.4, 4.5, 5.5, 6 and 9.0 mm drills; 90° countersink; M10 x 1 tap and wrench.
- A small milling machine for the windows and pockets in the rail bars, or a local machine shop; anodising by a local shop.
- Thread-locker, a straight edge, and a 2-part epoxy for sealing the carbon plate's edges.
- FDM printer that can print ASA (enclosure, heated bed); heat-set insert tip.
- Temperature-controlled soldering station of 100 W or more for 8 AWG; heat-shrink and heat gun; crimp tools for JST-GH.
- Multimeter, current-limited bench supply (at least 60 V, 5 A), feeler gauges, kitchen scale.
- Skills: careful marking and drilling to 0.2 mm, tapping, soldering heavy leads, and following the PX4 setup guide.
- A bench with good light and ventilation, and a non-flammable area with a lithium fire plan for any work with packs.

## 8. Where the numbers come from

- `cad/src/model.py`: every size and position, and the 720 constructability checks.
- `cad/drawings/KWC-DWG-001`: general arrangement (Rev P2); `KWC-DWG-101` to `109`: the making sketches.
- `docs/04-calcs/01-sizing.md` and `sizing.py` (KWC-CAL-001): loads, swap time, power, heat, altitude, mass and cost.
- `bom/bom.csv`: parts, specifications and prices.
- `docs/decisions/0001-trl2-review-decisions.md`, `0002-design-for-construction.md` and `0003-r9-core-mass.md`.

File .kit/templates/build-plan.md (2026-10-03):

---
doc_id: PRJ-BLD-001
title: Project prototype build plan
project: Project name
doc_type: Build plan
version: "0.1"
status: Draft
date: YYYY-MM-DD
author: Amish Chadha
license: CERN-OHL-S-2.0
revisions:
  - version: "0.1"
    date: YYYY-MM-DD
    author: Amish Chadha
    change: First build plan; design made constructable
---

# Project prototype build plan

**Plan, not yet built.** How to build the first proof-of-concept prototype, component by component. Building and testing to it is TRL 4 work. Decisions still to be made are kept in the design decisions register (`docs/06-design-decisions.md`), not here.

## 1. What you are building

Every component, pulled apart and numbered in build order

One short paragraph: what the prototype is, how many components, which are made and which are bought, and the main ways they are made.

## 2. What changed to make it buildable

| Component | The concept had | The buildable design has | Why |
| --- | --- | --- | --- |

## 3. Making the components

### 3.1 Component name

Making sketch

**What it is and what it is made from.**

**How to make it.**

1. Mark out ...
2. Cut ...

**How it fits the parts next to it.**

Close-up of the joint

**Check before moving on.**

## 4. Putting it together

### Step 1: ...

Step 1

## 5. First checks

| Check | Requirement | How | Pass when |
| --- | --- | --- | --- |

## 6. Safety stops

## 7. Tools, skills and workspace

## 8. Where the numbers come from

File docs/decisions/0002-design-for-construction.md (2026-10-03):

---
doc_id: KWC-DDR-002
title: Kitewright Core design for construction
project: Kitewright Core
doc_type: Design decision record
version: "0.1"
status: Draft
date: '2026-10-03'
author: Amish Chadha
license: CERN-OHL-S-2.0
revisions:
- version: "0.1"
  date: '2026-10-03'
  author: Amish Chadha
  change: Changes that make the concept physically buildable, with the reason for each; decided under Amish's 2026-10-03 pre-approval
---

# 0002: Design for construction

- **Date:** 2026-10-03
- **Status:** accepted. Decided by Amish under his pre-approval of 2026-10-03: "start with the first 14 repos from the list of 29 projects. I pre-approve the batch runs along with any recommendations you come up with. I also accept any cost overruns or variations from the assumed scope cost." and "Proceed with the remaining 15 scaffolds".

## Context

The scaffold described the core in words only: a stack that bolts into any frame, a payload mount of "a plain rail with a locking pin" and a DS-014 connector. It had no geometry, so nothing in it had been checked for how it is made or how it fixes to its neighbours. Writing the build plan (STANDARDS section 18) turned that description into parts that can be cut, drilled, printed or bought, and that fasten to each other. Amish's rule for this step (2026-09-30): "fix the design assumptions to match and be physically feasible". Every change keeps what the core does, its pitch and its patent design-arounds. The safety case is strengthened, not weakened: the second locking pin (KWC-DDR-001, D6) is part of it.

The model in `cad/src/model.py` runs 614 constructability checks (`python cad/src/model.py --check`): no two parts overlap, every part that must rest on another touches it, the shoe clears the plate by at least 0.25 mm and the spacer bars by 0.9 mm, the flight controller clears the lid by 5 mm, nothing but the corner spacers touches the frame deck, and nothing of the core enters the payload's neck zone below the lips. All pass.

## Decision

*Table 1. Changes from the concept to the constructable design.*

| # | Component | The concept had | The constructable design has | Why |
| --- | --- | --- | --- | --- |
| C1 | Payload rail | "A plain rail" with no shape | Two 200 mm rails, each a 10 x 6 mm spacer bar and a 30 x 3 mm lip bolted under the plate; 0.7 mm UHMW tape on the lips; shoe 5 mm thick, 0.3 mm gap above it, 1 mm at each side | Stock bar and sheet, drilled and screwed; the gap is set by stock thicknesses, not by machining |
| C2 | Locking pin | "A locking pin" | Two M10 x 1 indexing plungers in 28 x 30 x 15 mm blocks under the lips at the rear; 5 mm pins through 5.5 mm holes in lip, tape and shoe | A bought plunger needs a threaded block; under the lip it stays outside the payload's neck zone |
| C3 | End of travel | None | Two 12 mm front stops between plate and lip at the front of each rail, held by the rail's own screws | Aligns the pins with their holes without extra fixings |
| C4 | Payload connector | "A DS-014 connector" on the mount | A 0.3 m pigtail down through a 12 x 24 mm slot in the plate and an 18 x 28 mm notch in the shoe's front edge; plug pushed into the payload's socket by hand | A sliding shoe cannot mate a 40-pin connector reliably; the notch lets the shoe pass the cable |
| C5 | Fixings under the plate | Not shown | M3 self-clinching nuts pressed in from below, flush underneath, for the lid, standoffs and power board | The shoe slides 0.3 mm under the plate, so nothing may stand proud there |
| C6 | Core to frame | "Bolts into any frame" | Plate hangs under the deck on four M4 bolts on 220 x 130 mm with 16 x 8 mm spacers; lid rises through a 200 x 112 mm deck opening | Gives the rail a clear path under the frame and puts payload load into the frame's hard points |
| C7 | Flight controller mounting | Not shown | Four 25 mm standoffs, four silicone dampers, a 2 mm G10 damping plate; controller on nylon screws above the power board | Vibration isolation, and room for the power board beneath |
| C8 | Avionics cover | "Cold-rated avionics enclosure" | Printed ASA lid 168 x 92 x 62 mm with a 180 x 108 mm flange on a 1 mm foam gasket, six M3 screws on the long sides only | The flange clears the front stop nuts and the frame deck opening |
| C9 | Power leads | Not shown | Four 8 AWG leads out through two rubber grommets in the lid's rear wall; AS150 plugs soldered after the lid is on | A plug will not pass a grommet; soldering last avoids a split grommet |
| C10 | GNSS | "Mast-mounted" | Removable 10 mm carbon tube in a printed boss on the lid, GNSS 231 mm above the plate, thumbscrew | Clear of power wiring; comes off for transport |

## Consequences

- `cad/src/model.py`, the STEP and STL exports, drawing KWC-DWG-001 Rev P1, the making sketches KWC-DWG-101 to 108, the build plan pictures and the concept media are all generated from the changed model.
- `bom/bom.csv` gains the spacer bars, lips, tape, stops, pin blocks, second plunger, clinch nuts, damping parts, gasket and grommets.
- KWC-CAL-001 uses the changed geometry. The structure sized for making in sheet and bar weighs more than R9 allows; that is put to Amish in `docs/REVIEW.md`, not decided here.
- The frame interface of C6 is a shared assumption with Kitewright Lift and Kitewright Range (Cross-repo actions in `docs/REVIEW.md`).

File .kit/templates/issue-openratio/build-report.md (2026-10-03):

---
name: Build report
about: Tell us what happened when you built, printed or tested part of this design
title: "Build report: "
labels: build-report
---

This is a research and educational prototype, not a medical device. It is a TRL 3 concept and is not released for fabrication. If you build any part of it, you do so at your own risk. Reports help everyone.

**What you built** (part, sub-assembly or test)

**Materials, tools and settings**

**What worked**

**What did not work, with photos or measurements if you have them**

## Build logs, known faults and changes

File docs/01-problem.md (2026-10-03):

---
doc_id: KWC-PRB-001
title: Kitewright Core problem statement
project: Kitewright Core
doc_type: Problem statement
version: "0.2"
status: Draft
date: '2026-10-03'
author: Amish Chadha
license: CERN-OHL-S-2.0
revisions:
- version: "0.1"
  date: '2026-09-30'
  author: Amish Chadha
  change: Initial scaffold
- version: "0.2"
  date: '2026-10-03'
  author: Amish Chadha
  change: Open questions answered by the decisions of KWC-DDR-001 (Amish's 2026-10-03 pre-approval); budget worded as a value-engineering target; co-design candidate named
---

# Kitewright Core problem statement

Every drone project for mountain rescue or survey ends up rebuilding the same things: autopilot setup, power, radio, a payload mount and cold-weather tuning. Commercial platforms solve this inside closed ecosystems that small teams cannot afford, inspect or adapt.

## The problem

Demand is real. Drones have helped rescue more than 1,000 people ([DJI, 2023](https://www.dji.com/media-center/announcements/dji-records-more-than-1000-people-rescued-by-drones-globally)), and heavy-lift drones now work above 5,000 m on Everest ([DJI, 2024](https://www.dji.com/media-center/announcements/dji-completes-world-first-drone-delivery-tests-on-mount-everest-en)). But mountain conditions stretch every part. The standard atmosphere at 5,000 m gives 60% of sea-level air density at -17.5 °C ([Engineering ToolBox](https://www.engineeringtoolbox.com/standard-atmosphere-d_604.html)), so rotors work harder while batteries deliver less. The Mavic Pro that found Rick Allen was flying far above its rated ceiling ([DroneDJ, 2018](https://dronedj.com/2018/07/16/mountaineer-rick-allen-was-feared-dead-on-broad-peak-but-a-dji-mavic-pro-drone-found-him-alive/)).

The closed route works but locks teams in. The Matrice 350 RTK is rated to 5,000 m with standard propellers and -20 °C ([Advexure](https://advexure.com/products/dji-matrice-350-rtk)), at USD 14,814 plus USD 899 per battery ([DroneFly](https://www.dronefly.com/products/dji-tb65-intelligent-flight-battery-m350)). The open route has strong parts: PX4 under BSD 3-Clause ([GitHub](https://github.com/PX4/PX4-Autopilot)), the Pixhawk standards including DS-014 ([Pixhawk Standards](https://github.com/pixhawk/Pixhawk-Standards)), and ArduPilot for fixed wing and VTOL ([ArduPilot](https://ardupilot.org/plane/docs/quadplane-overview.html)). What is missing is an integrated, documented core, with its power bus, mount, radios and altitude tuning specified once, that every frame and payload in a family can rely on.

## Users and context

| User | Need | Context |
| --- | --- | --- |
| Mountain rescue teams | A platform they can repair and adapt, with payloads that swap in the field | Search at 3,000 to 6,000 m, often in cold and wind |
| Glacier and hazard researchers | An inspectable platform whose logs, power and sensors are documented | Seasonal field campaigns at glacial lakes |
| Disaster response groups and NGOs | A lower-cost, multi-role drone that is not tied to one vendor | Floods, landslides and road cuts in mountain regions |
| Payload developers and students | A published mechanical, electrical and software interface to build against | University labs, makerspaces, small companies |

## Operating environment

- Operation from sea level to 5,000 m (design target), with growth to 6,000 m to be assessed.
- Ambient -20 to +45 °C (-4 to +113 °F) (target); snow, rain, dust and UV.
- Wind up to about 10 m/s in normal operation (target); gusts in mountain valleys.
- Remote sites without mains power; batteries charged from vehicles or generators.
- Radio links in steep terrain with frequent loss of line of sight.

## Constraints

- Value-engineering target of USD 5,000 for the core, including avionics, radios, a ground station setup and spares (a hypothetical control target, not a limit; STANDARDS section 18).
- Upstream PX4 (or ArduPilot) with parameters and documented modules; no private fork of the flight stack.
- Payload mount follows Pixhawk DS-014 electrically, with a plain rail and locking pin mechanically; no bayonet.
- Power bus runs from ColdCell packs with external film heaters and a BMS thermostat; any tether input is fixed voltage with onboard DC-DC conversion.
- Same core, unchanged, in the Lift and Range frames.
- Hardware under CERN-OHL-S-2.0; software under a licence compatible with PX4 (BSD 3-Clause) or ArduPilot (GPLv3).

## Out of scope

- Airframes (Kitewright Lift and Kitewright Range) and payloads (AvalancheScout, LakeWatch and others), which are sibling repos.
- Caged confined-space frames (deferred after the patent screen).
- Hybrid generator, fuel-cell or combustion power.
- Beyond-visual-line-of-sight approvals, satellite links and remote ID certification at this TRL.
- Aviation certification (FAA Part 107, EASA, India DGCA Drone Rules 2021) at this TRL; to be addressed if prototypes progress.
- Any weapon, targeting or military payload.

## Prior work

| Prior work | What it does | Gap for these users | Source |
| --- | --- | --- | --- |
| PX4 Autopilot | Open flight control software under BSD 3-Clause, governed by the Dronecode Foundation | Software only; no reference airframe, power bus or cold-weather integration | [link](https://github.com/PX4/PX4-Autopilot) |
| Pixhawk Payload Bus standard (DS-014) | Open standard with a 40-pin connector carrying Ethernet, USB 2.0, CAN FD, UART, trigger, PPS and battery power, plus MAVLink payload protocols | An interface standard, not a built mount or core; licence terms still to confirm | [link](https://dronecode.org/announcing-the-pixhawk-payload-bus-open-standard/) |
| DJI Matrice 350 RTK | Closed enterprise drone, 55 min flight, -20 to 50 °C, 5,000 m ceiling with standard propellers, USD 14,814 | Closed payload and battery ecosystem; cost beyond many mountain teams | [link](https://advexure.com/products/dji-matrice-350-rtk) |
| DJI TB65 self-heating battery | 263.2 Wh pack that heats itself below 5 °C, rated -20 to 50 °C, USD 899 | Works only in DJI aircraft; used in pairs | [link](https://www.dronefly.com/products/dji-tb65-intelligent-flight-battery-m350) |
| ArduPilot QuadPlane | Open flight control for fixed wing aircraft with VTOL motors | Firmware only; no shared hardware core across frames | [link](https://ardupilot.org/plane/docs/quadplane-overview.html) |

## Co-design

A mountain rescue organisation or high-altitude research group working in the Himalaya or Karakoram, such as a state disaster response force unit or a university glaciology team, that can define missions, test at altitude and review the payload interface. First candidate to approach (not agreed): a university glaciology group in Jammu and Kashmir that already surveys glacial lakes in the Kashmir Himalaya, with a state disaster response force unit in the same region as the second (KWC-DDR-001, D13).

> **Safety:** Field work with prototypes happens only with a partner that holds the local flying permissions and runs its own safety briefing; nothing here is an approval to fly.

## Open questions answered at TRL 3

*Table 1. The scaffold's open questions and the decisions that answer them (KWC-DDR-001, decided under Amish's 2026-10-03 pre-approval).*

| Question | Answer | Decision |
| --- | --- | --- |
| Under what licence is DS-014 published, and can its connector be used freely? | Proceed with the DS-014 connector and pinout; confirm the licence before the connector is bought; if it restricts reuse, keep the same 40-pin connector with Kitewright's own open pinout | D12 |
| PX4 or ArduPilot as the primary stack? | PX4 for the whole family; ArduPilot documented as the alternative | D1 |
| Which radio bands and power levels at target sites? | 900 MHz class radios set per country; for India the 865 to 867 MHz licence-exempt band is the first candidate, to confirm with the partner | D10 |
| What payload mass and power classes? | One class for version 1: 5 kg and 100 W | D4 |
| Remote ID and flight logging? | Every flight logged on the controller; a remote ID module goes on the CAN bus when a country's rules require it | D14 |

## Safety

> **Safety:** The problem involves lithium packs, spinning propellers and loads carried over people and terrain. Every Kitewright document that describes these keeps a safety section; the core's precis (KWC-PRC-001) and build plan (KWC-BLD-001) set out the hazards and the safety stops. Civilian use only; no weapons, targeting or military payloads.

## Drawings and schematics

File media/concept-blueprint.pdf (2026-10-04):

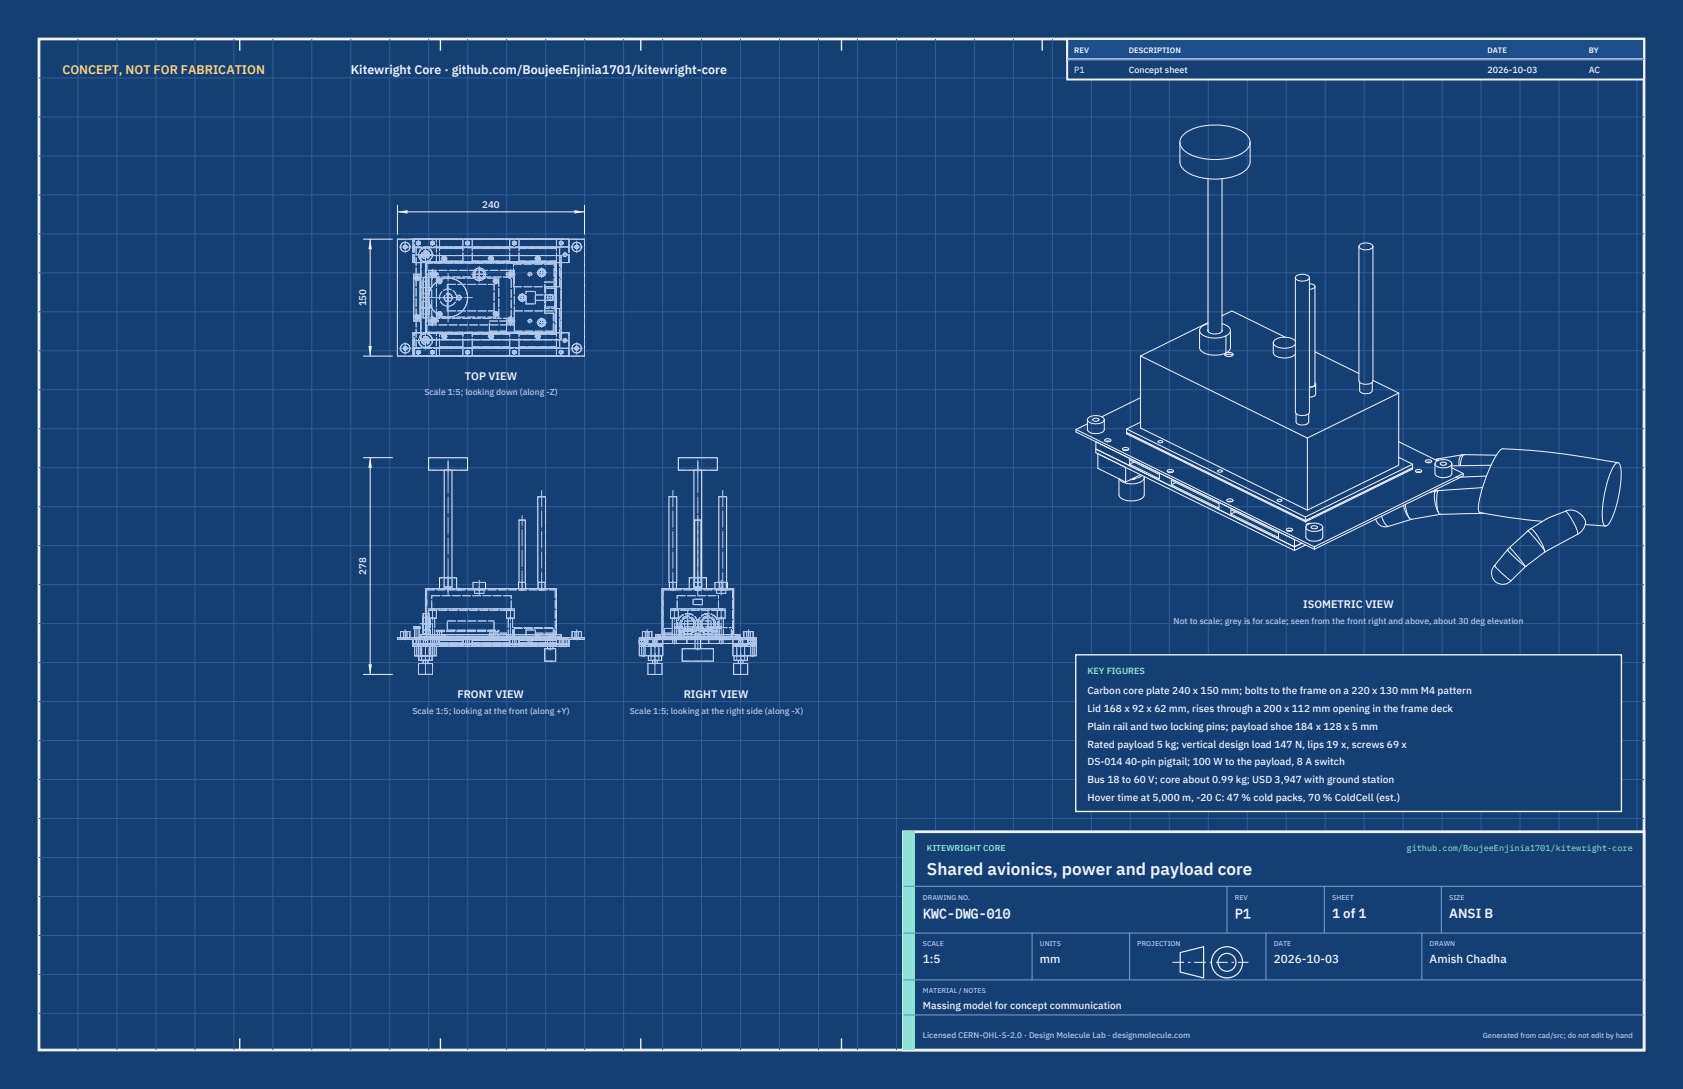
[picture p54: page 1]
CONCEPT, NOT FOR FABRICATION; Kitewright Core · github.com/BoujeeEnjinia1701/kitewright-core; FRONT VIEW; TOP VIEW; RIGHT VIEW; ISOMETRIC VIEW; REV; DESCRIPTION; DATE; Concept sheet; KITEWRIGHT CORE; github.com/BoujeeEnjinia1701/kitewright-core; DRAWING NO. KWC-DWG-010; REV P1; SHEET 1 of 1; SIZE ANSI B; SCALE 1:5; UNITS mm; PROJECTION; DRAWN Amish Chadha; Licensed CERN-OHL-S-2.0 · Design Molecule Lab · designmolecule.com; Generated from cad/src; do not edit by hand

Scale 1:5; looking down (along -Z)

Not to scale; grey is for scale; seen from the front right and above, about 30 deg elevation

KEY FIGURES
Carbon core plate 240 x 150 mm; bolts to the frame on a 220 x 130 mm M4 pattern
Lid 168 x 92 x 62 mm, rises through a 200 x 112 mm opening in the frame deck
Plain rail and two locking pins; payload shoe 184 x 128 x 5 mm
Rated payload 5 kg; vertical design load 147 N, lips 19 x, screws 69 x
DS-014 40-pin pigtail; 100 W to the payload, 8 A switch
Bus 18 to 60 V; core about 0.99 kg; USD 3,947 with ground station
Hover time at 5,000 m, -20 C: 47 % cold packs, 70 % ColdCell (est.)

Scale 1:5; looking at the front (along +Y)

Scale 1:5; looking at the right side (along -X)

Shared avionics, power and payload core

MATERIAL / NOTES
Massing model for concept communication

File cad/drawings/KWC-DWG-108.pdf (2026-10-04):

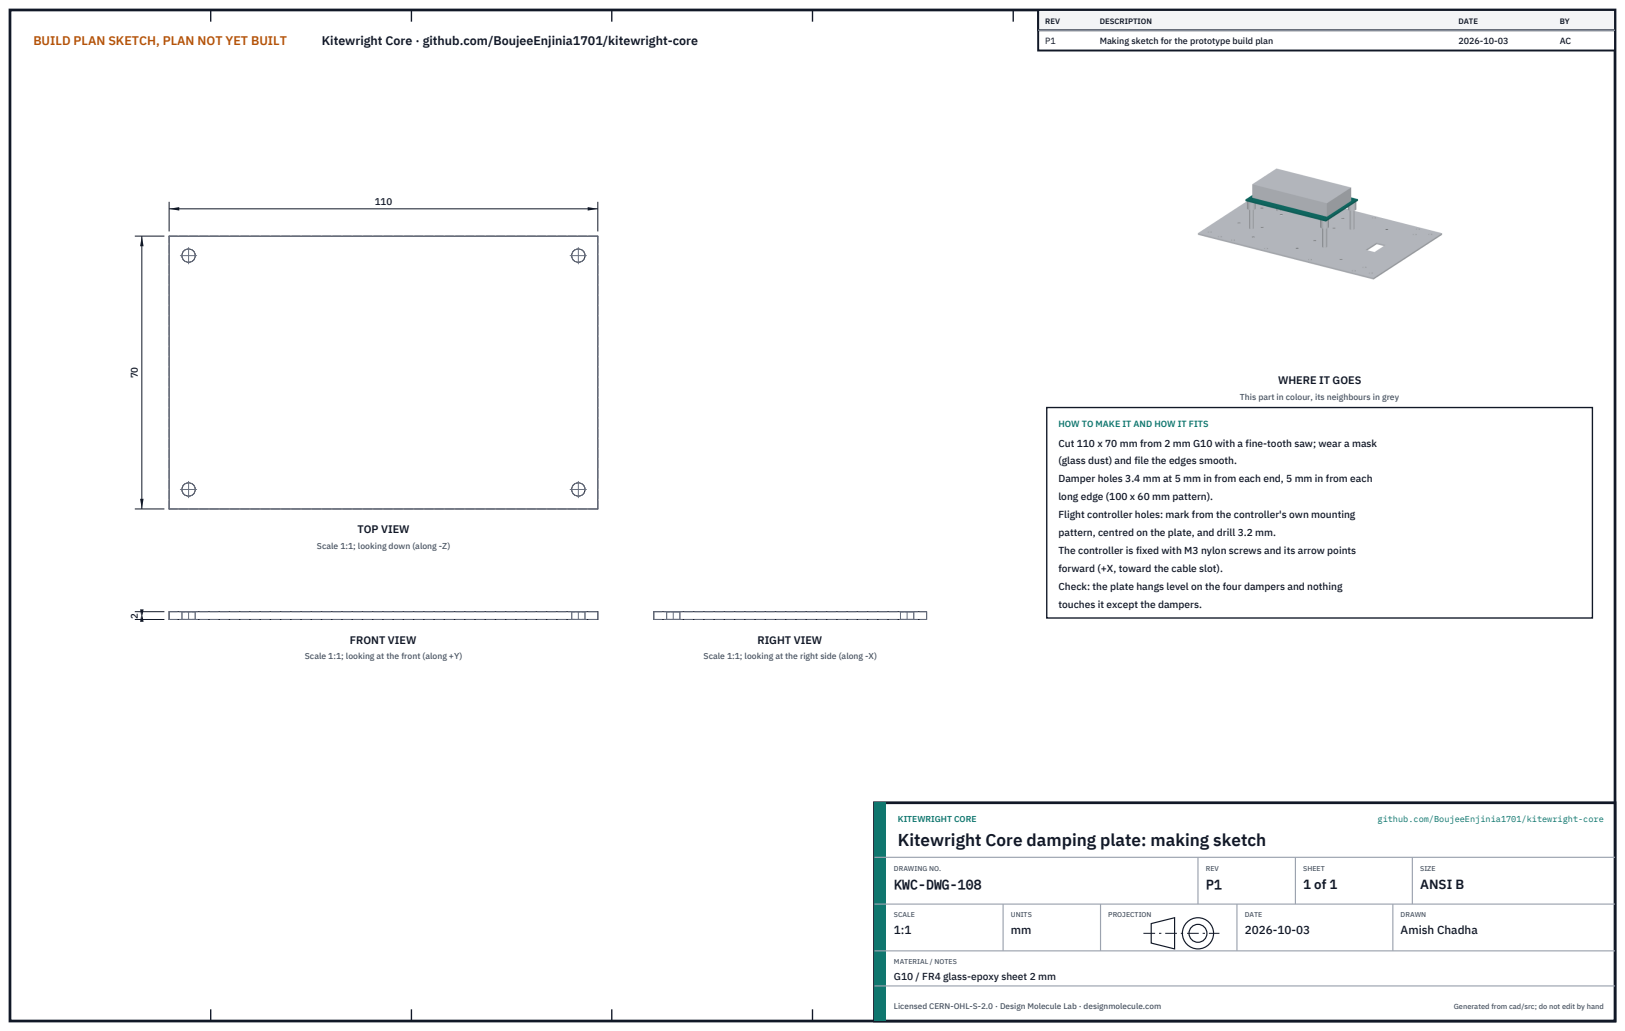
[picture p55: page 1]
BUILD PLAN SKETCH, PLAN NOT YET BUILT; Kitewright Core · github.com/BoujeeEnjinia1701/kitewright-core; FRONT VIEW; TOP VIEW; RIGHT VIEW; REV; DESCRIPTION; DATE; Making sketch for the prototype build plan; KITEWRIGHT CORE; github.com/BoujeeEnjinia1701/kitewright-core; DRAWING NO. KWC-DWG-108; REV P1; SHEET 1 of 1; SIZE ANSI B; SCALE 1:1; UNITS mm; PROJECTION; DRAWN Amish Chadha; Licensed CERN-OHL-S-2.0 · Design Molecule Lab · designmolecule.com; Generated from cad/src; do not edit by hand

WHERE IT GOES

This part in colour, its neighbours in grey

HOW TO MAKE IT AND HOW IT FITS
Cut 110 x 70 mm from 2 mm G10 with a fine-tooth saw; wear a mask
(glass dust) and file the edges smooth.
Damper holes 3.4 mm at 5 mm in from each end, 5 mm in from each
long edge (100 x 60 mm pattern).
Flight controller holes: mark from the controller's own mounting
pattern, centred on the plate, and drill 3.2 mm.
The controller is fixed with M3 nylon screws and its arrow points
forward (+X, toward the cable slot).
Check: the plate hangs level on the four dampers and nothing
touches it except the dampers.

Scale 1:1; looking down (along -Z)

Scale 1:1; looking at the front (along +Y)

Scale 1:1; looking at the right side (along -X)

Kitewright Core damping plate: making sketch

MATERIAL / NOTES
G10 / FR4 glass-epoxy sheet 2 mm

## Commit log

2026-10-03 Kitewright Core at TRL 3: constructable design (kit 1.7.0)
    Problem, concept and requirements; sizing calculations; CAD model, STEP and STL; general arrangement drawing; bill of materials; build plan with making sketches, joint close-ups and step pictures; design decisions register (design choices decided under Amish's 2026-10-03 pre-approval; requirement decisions open for Amish); TRL 2 and TRL 3 review; photoreal renders and storefront card. Private until Amish opens it.
    [bom.csv, kitewright-core-assembly.step, kitewright-core-fc-plate.stl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]
2026-10-04 Carry Amish's round 2 requirement decisions into the design
    Amish approved all 47 recommendations on 2026-10-03 ("i approve all of the 47 recommendations provided by you. Execute them."). Each repo gains a decision record (DDR-003, or the next free number for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
    [bom.csv, kitewright-core-assembly.step, kitewright-core-lid.stl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]
2026-10-04 Carry Amish's round-2 and round-3 decisions into the design
    Amish approved all 46 round-2 recommendations ("i agree with all the 46 recommendations you provided. please proceed.") and all round-3 recommendations ("For round 3, I agree with all your proposed r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
    [bom.csv, kitewright-core-assembly.step, kitewright-core-pin-block.stl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]

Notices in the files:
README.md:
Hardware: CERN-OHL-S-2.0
